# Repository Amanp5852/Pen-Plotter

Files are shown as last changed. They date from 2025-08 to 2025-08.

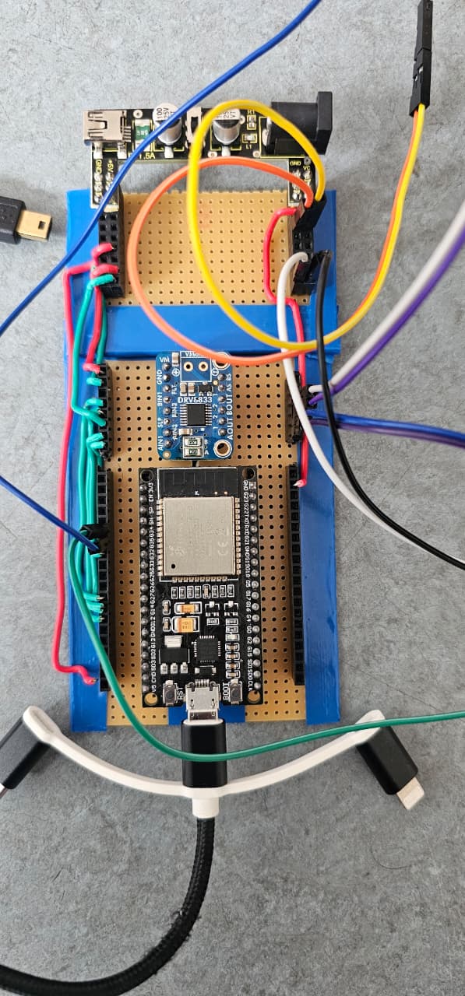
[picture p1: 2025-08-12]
Electrical_Connection/Electrical_Hardware.jpg

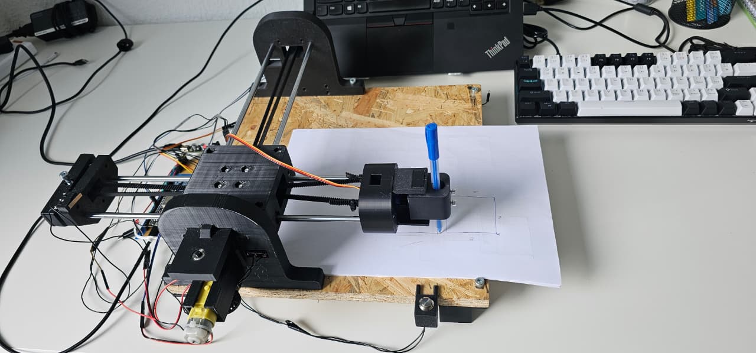
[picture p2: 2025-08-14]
Videos and Photos/Photo_Of__Pen_Plotter.jpg

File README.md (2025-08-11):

**CoreXY ESP32 Pen Plotter**
This project is a fully functional CoreXY-based pen plotter designed for precision, speed, and ease of use. It brings together mechanical engineering, electronics, control systems, and intuitive software to deliver a reliable plotting experience.

Mechanical & Hardware Features
CoreXY motion system for high-speed, precise X/Y movement with reduced inertia.

GT2 timing belts and precision drivers for smooth, consistent motion.

Custom 3D-printed components for the frame, carriage, belt tensioners, and pen holder.

Servo-driven Z-axis for controlled pen up/down motion.

Limit switches for repeatable homing and reference positioning.

Emergency stop to instantly halt motion and return safely to the home position.

Electronics & Control
Powered by an ESP32 microcontroller for fast processing and wireless capability.

PID-based closed-loop control with real-time feedback from optical encoders.

Encoder feedback ensures accurate path following, even during complex or long plots.

Software & User Interface
Custom firmware built from the ground up for CoreXY kinematics and closed-loop PID control.

User-friendly UI for easy operation — allowing you to control movements, start/stop plotting, trigger homing, and manage the emergency stop with minimal learning curve.

UI designed for accessibility, making it easy for beginners and efficient for advanced users.

Safety & Reliability
Integrated emergency stop ensures quick reaction to errors or obstructions.

Homing process guarantees consistent starting points for all drawings.

Sturdy yet lightweight structure ensures durability without sacrificing portability.

This pen plotter is not just a demonstration of precise motion control — it’s a complete system that merges mechanical design, control theory, and user-centric software into a versatile plotting tool. Whether for art, technical drawings, or experimental automation, it delivers consistent and repeatable results while keeping operation intuitive and safe.plotted artwork or technical drawings.

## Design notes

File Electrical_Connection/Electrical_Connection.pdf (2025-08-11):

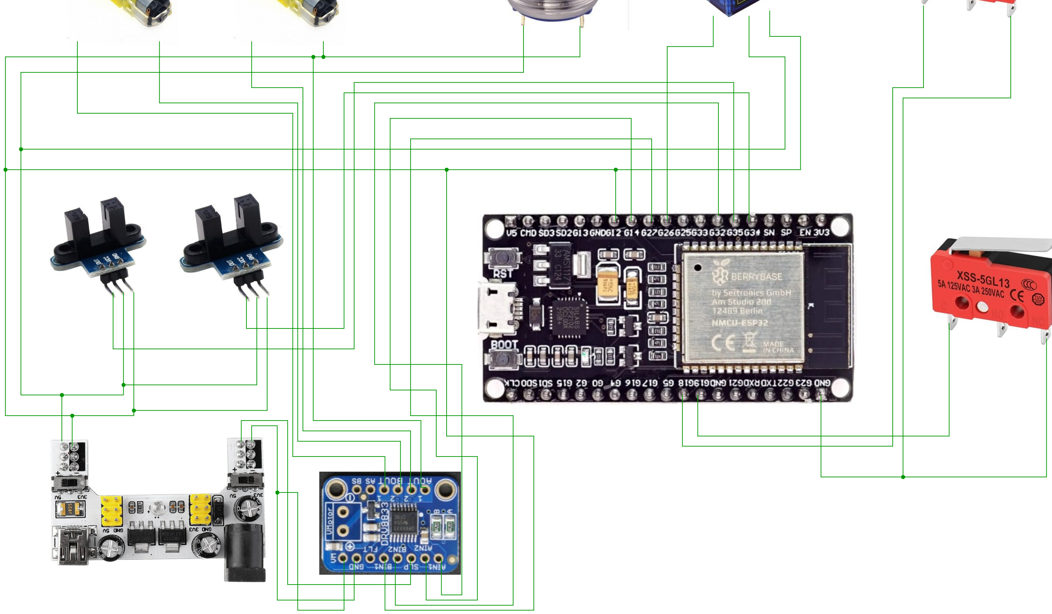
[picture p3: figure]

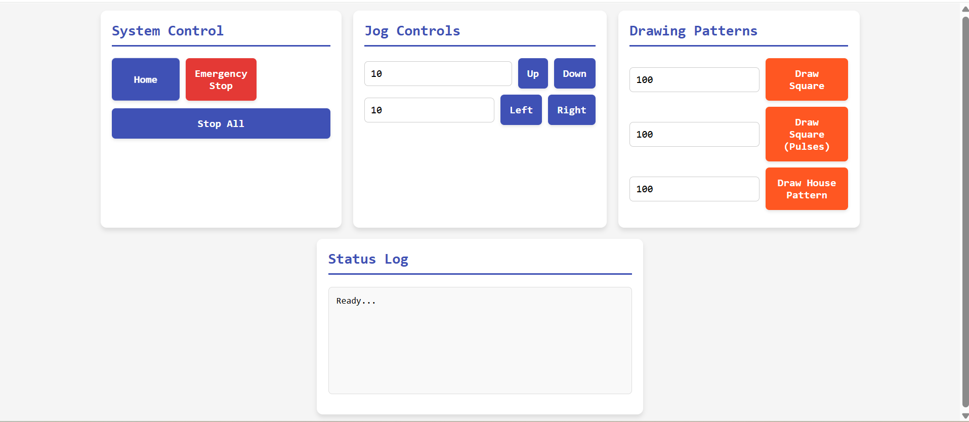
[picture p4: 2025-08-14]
Videos and Photos/Web_UI.png

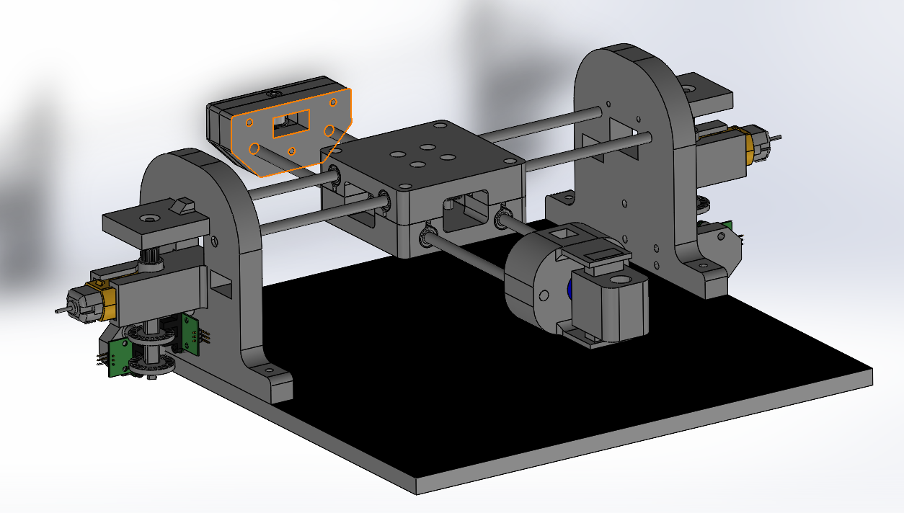
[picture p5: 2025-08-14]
Videos and Photos/CAD_Photo.png

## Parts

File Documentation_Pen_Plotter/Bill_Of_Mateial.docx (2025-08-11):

# Index of Change

Version | Description of Change | Name | Date
1.0 | Initial | Atharva Bhosale | 2025-06-20

# Table of Contents

Index of Change 1

Table of Contents 1

1 Subject 1

2 Bill of Material 2

3 Conclusion 4

# 1 Subject

A pen plotter is a type of computer-controlled device that uses pens or markers to create precise and accurate drawings on paper. This project aims to develop a functional pen plotter using specific components and technologies that showcases the integration of hardware, software, and mechanical components to achieve a specific task.

This document presents the Bill of Materials (BOM) for the pen plotter developed and fabricated by us as a part of our Workshop Mechatronics project. This product combines hardware, software, and mechanical components to create precise and accurate drawings on paper.

The BOM serves as a comprehensive inventory list, detailing the specific components and technologies utilized in the construction of the pen plotter, highlighting their crucial role in achieving the desired functionality and performance.

The Bill of Materials presented in this document provides a comprehensive inventory of the key components and technologies employed in the construction of the pen plotter.

These carefully selected components and technologies are instrumental in achieving the precise and accurate drawing capabilities of the pen plotter, showcasing its exceptional functionality and performance.

# 2 Bill of Material

Bill of Materials
Item | Description | Material | Source | QTY | Measurement | Unit Price | | Total Price

Mechanical Components
M01 | Pulley 2GT | Aluminium | Temu | 5 | piece | € 1,15 | | € 5,76
M02 | Heat Set Inserts | Steel | Temu | 200 | piece | € 0,025 | | € 4,45
M03 | Neodymium Magnet | Magnet | Conrad | 1 | piece | € 6,99 | | € 6,99
M04 | Ball Bearing | Steel | Conrad | 2 | piece | € 1,29 | | € 2,58
M05 | Geared Pulley | Steel | University | 2 | piece | € 0,20 | | € 1,00
M06 | 3D Printed Feet | PLA | University | 4 | piece | € 0,10 | | € 1,20
M07 | Belt | Rubber | University | 1 | meter | € 0,20 | | € 2,40
M08 | Smooth rods 6mm | Steel | University | 4 | meters | € 0,15 | | € 1,50
M09 | Cable ties | Plastic | Hellweg | 100 | piece | € 0,025 | | € 2,50
M10 | Super Glue | Glue | Tedi | 1 | piece | € 1,00 | | € 1,00
M11 | M3 *20mm | Steel | Hellweg | 16 | piece | € 0,211 | | € 3,39
M12 | M3 *10mm | Steel | Hellweg | 16 | piece | € 0,19 | | € 3,19
M13 | M3 Nuts | Steel | Hellweg | 20 | piece | € 0,018 | | € 3,79
M14 | M4 washers | Plastic | Hellweg | 25 | piece | € 0,079 | | € 1,99
M15 | M4 Screws | Steel | University | 4 | piece | € 0,00 | | € 0,00
| | | | | | | Subtotal | | € 41,74

Electrical Components
E01 | Bread Board | | University | 2 | Piece | € 0 | | € 0
E02 | Connect Socket Strip | | Conrad | 12 | Piece | € 0,29 | | € 3,48
E03 | Dupont Connector Kit | | Berrybase | 1 | Piece | € 14,85 | | € 14,85
E04 | Motor Driver | | University | 1 | Piece
E05 | ESP32 Development board | | University | 1 | Piece
E06 | TT Motor Encoder | | University | 2 | Piece
E07 | Servo motor | | University | 2 | Piece
E08 | Cable for Motor Driver | | University | 1 | Piece
E09 | Cable for Power Supply | | University | 1 | Piece
E10 | Jumper cables | | University | 1 | Piece
E11 | DC Motor | | University | 2 | Piece
E12 | Power Supply Unit | | University | 1 | Piece
E13 | Hall Effect Sensor | | University | 1 | Meter
E14 | Microswitch RED | | University | 4 | Piece
E15 | Adaptor 12V | | Amazon | 1 | Piece | € 15 | | € 15
E16 | Limit Switches | | Univesity | 4 | Piece
E17 | Perfboard | | Conrad | 1 | Piece | € 2,49 | | € 2,49
| | | | | | | Subtotal | | € 35,82

3D Printed Components
P01 | Encoder Wheel | PLA | University Lab | 4 | Piece | € 1,00 | | € 2,00
P02 | GT2 15T Motor Pulley | PLA | University Lab | 2 | Piece | € 1,00 | | € 2,00
P03 | Carriage | PLA | University Lab | 1 | Piece | € 5,0 | | € 5,00
Item | Description | Material | Source | QTY | Measurement | Unit Price | | Total Price
P04 | Pulley Tensioner | PLA | University Lab | 1 | Piece | € 6.00 | | € 6,00
P05 | Motor Support Fixture | PLA | University Lab | 2 | Piece | € 11.00 | | € 22,00
P06 | Pen Holder Fixture | PLA | University Lab | 1 | Piece | € 8.00 | | € 8,00
P07 | Base Plate | PLA | University Lab | 1 | Piece | € 20.00 | | € 20,00
P08 | Pulley Tensioner | PLA | University Lab | 1 | Piece | € 16.00 | | € 16,00
| | | | | | | Subtotal | | € 61
Grand total | | | | | | | | | € 138.56

# 3 Conclusion

The total cost of manufacturing the pen plotter is approximately 175 euros, which is significantly less than the permitted cap of 200 euros and in accordance with User requirements.

– end of document –

Bill of Material (BOM) XY-Pen Plotter XYPP_14_006-BOM.docx Doc. # XYPP Version: 1.0 Date: 2025-06-20 page: of Project #: XYPP

B|BRAUN Sharing Expertise CoE Automateted Infusion Systems Testplan Produkt Titel D:\MERO\SEM 2\Workshop_Mechatronics_II_MERO_2023\Documentation\16.07.23\XYPP_14_006-BOM.docx Dokument-Nr.: Nr. eingeben Version: X.0 Datum: 200X-XX-XX Seite: von Änderung-Nr.: CXX-YYY

Validation Report XY-Pen Plotter Doc. # XYPP Version: 1.0 Date: 2025-06-20 page: of Project #: XYPP

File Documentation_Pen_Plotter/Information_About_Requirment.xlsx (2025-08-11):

Project Name |  |  | XY-Pen Plotter- MERO 24
Date |  |  | WS24/25
Version |  |  | V2
Group Name |  |  | MER0 Team 10
Group Members |  |  | Aman Patel, Vighnesh Deshmukh, Atharva Bhosale, Rishab deshkar, Deep Shah
User Requirement |  |  |  |  |  |  | Technical Specification |  |  |  |  |  |  |  | Design Specification |  |  |  |  |  |  | Verification Protocol |  |  |  |  |  |  | Verification Report |  |  |  |  |  |  |  |  |  | Validation Protocol |  |  |  |  |  | Validation Protocol
UR # | module | Title | User Requirement | Remark | Domain (HW/SW/ME/all) | Must / Wish | TS # | ref. to UR # | module | Title | Technical Requirement | Remark | Domain (HW/SW/ME/all) | Must / Wish | DS # | ref. to TS # | module | Reference (# bill of materials, article # supplier part, ref. doc # etc..) to implementation | Description | Remark | Domain (HW, SW, ME, all) | VerP # | ref to TS # | module | test procedure (description of routine) | verification criterion | ref. # (i.e. test protocol,etc.) | Domain (HW/SW/ME/all) | VerR # | ref. to VerP # | module | test function (to be copied from verification protocol) | nominal criterion, target value | actual value | criterion passed / failed | remark | ref. # (i.e. test report, etc.) | Domain (HW/SW/ME/all) | ValP # | ref. to UR # | module | validation procedure (description of routine) | ref. # (i.e. validation protocol, customer test, etc..) | vaidation criteria | ValR # | ref. to ValP # | module | criteria passed / failed | ref. # (i.e. test report, etc.)
UR_1 | General | Intended Use | The XY-pen plotter is designed to draw a Nikolaus house based on programmed instructions and is intended for educational use by MeRo Master’s students in the university laboratory. |  | all |  | TS_1 | UR_1 | General | Intended Use | The pen plotter can be used by the students to draw niclolaus house. |  | all |  | DS_1 | TS_1 | General | M01-M16, E01-E16, P01-P07 | The system uses DC motors with encoders to drive the X and Y axes and a servo motor for Z-axis (pen lift). An ESP32 microcontroller interprets programmed code instructions for the Nikolaus house and controls motor speed and direction. The interface allows students to upload drawing commands from a PC or mobile device through Wi-Fi. |  | all | VerP1 | TS_1 | General | Upload Nikolaus house code via Wi-Fi; observe drawing behavior. | Verify drawing accuracy and instruction interpretation via ESP32. | Test protocol doc# 01_MERO_VerP | all |  | VerP1 | General | Verify drawing accuracy and instruction interpretation via ESP32. | Pen plotter completes Nikolaus house with proper scale, direction, and without manual intervention. | Pen Plotter completes Nikolaus Hause but with some errors in corner matching. (Atleast at the initial run) | Passed (Still optimization is required) |  | Test protocol doc# 01_MERO_VerP | all | ValP 1 | UR01, UR10, UR11 | General | Upload Nikolaus House drawing code via GUI. Run plot. Repeat 10 times and overlay outputs to check dimensional accuracy. | ValP_01 | All 10 plots complete without error; overlay deviation ≤ ±3mm | VaIR1 | ValP_01 | General | Passed
UR_2 | General | Focus Group (User and Client) | Laboratory, Academic and Research institutions, Industries. |  | HW |  | TS_2 | UR_2 | General | Focus Group (User and Client) | The pen plotter is designed for Laboratory, Academic and Research institutions, Industries to use. |  | HW |  | DS_2 | TS_2 | General | M01-M16, E01-E16, P01-P07 | Design the system with modular hardware and open-source firmware for ease of use, modification, and learning in educational and research institutions. |  | HW | VerP2 | TS_2 | General | Attempting hardware module replacement; test firmware re-flashing (During the testing of the codes for refinement) | Assess modularity and open-source accessibility. |  | HW |  | VerP2 | General | Assess modularity and open-source accessibility. | User modifies hardware and uploads custom firmware within 10 minutes. | Made the input code run in order to optimize the system. Also changed many parts and assembly carried out within the range of 10 minutes | Passed |  |  | HW | ValP 2 | UR07, UR23, UR39 | Functional & non functional Requirement | Allow 2 non-project students to operate the GUI. Ask them to plot Nikolaus House and perform pen-up/pen-down. | VaIP_02 | User can complete task independently in <5 min after <2 min instruction | VaIR 2 | VaIP_02 | Functional & non functional Requirement | Passed
FOCUS APPLICATION
UR_3 | Use Cases | Focus Application | The plotter must draw the Nikolaus house continuously without any interruptions |  | all |  | TS_3 | UR_3 | Use Cases | Focus Application | The Nicolaus house can be drawn without any difficulties. |  | all |  | DS_3 | TS_3 | Use Cases | M01-M16, E01-E16, P01-P07 | Implement buffer handling and continuous motor control to ensure uninterrupted drawing operations; incorporate fault-tolerant firmware to recover from minor disturbances without halting. |  | all | VerP3 | TS_3 | Use Cases | Introduce signal noise or small power dip. Monitor for continued operation. | Verify uninterrupted operation under minor disturbances. |  | all |  | VerP3 | Use Cases | Verify uninterrupted operation under minor disturbances. | Drawing continues without stopping or significant deviation. | The amount of the vibration measured was minimal, not have means to provide quantitative value. | Passed |  |  | all | VaIP 3 | UR06, UR14, UR26 | Functional & non functional Requirement | Place 1kg weight on center carriage for 1 hour. Measure deflection using Vernier caliper. | ValP_03 | Deflection under load < 1.5mm after 1hr | VaIR 3 | ValP_03 | Functional & non functional Requirement | Passed
UR_4 | Use Cases | Focus Application | The user should be able to run the plotter without the pen touching the surface, for testing. |  | HW |  | TS_4 | UR_4 | Use Cases | Focus Application | In dry-run mode, Z-axis servo stays in “pen up” position throughout the plot to simulate movement without drawing. |  | all |  | DS_4 | TS_4 | Use Cases | M01-M16, E01-E16, P01-P07 | Firmware includes a dry-run flag that disables Z-axis pen-down commands. Servo is locked in the “pen up” PWM signal range. Verified through V&V dry-run testing. |  | HW | VerP4 | TS_4 | Use Cases | Enable dry-run; command plot of Nikolaus house giving the hard coding to implement. Check for no pen contact. | Validate dry-run feature. | Test protocol doc# 04_MERO_VerP | HW |  | VerP4 | Use Cases | Validate dry-run feature. | Plot completes in air without touching surface. | Plot completes the dry run with no actuation of Z axis | Passed |  | Test protocol doc# 04_MERO_VerP | HW | VaIP 4 | UR08, UR32, UR42 | Functional & Market requirement | Disassemble plotter. Replace motor, pen holder, and tensioner using STL parts and bolts. Time the process. | VaIP_4 | Full disassembly and reassembly <25 min. No tools except hex key. | VaIR 4 | VaIP_4 | Functional & Market requirement | Passed
APPLICATION SITE
UR_5 |  | Application Site (Industrial, Home, etc.) | The pen plotter must be suitable and safe for use in typical indoor educational and lab environments. |  | all |  | TS_5 | UR_5 |  | Application Site (Industrial, Home, etc.) | The pen plotter shall operate in 15–30 °C, ≤60% humidity, emit ≤50 dB noise, and comply with IEC 61010 indoor safety standards. | Environmental conditions comply with IEC 61010 for indoor educational equipment—ensuring safe operation at 15–30 °C, ≤60% humidity, and noise emissions ≤50 dB for classroom/lab use. | all |  | DS_5 | TS_5 |  | M01-M16, E01-E16, P01-P07 | Use enclosed ABS housing for IEC 61010 compliance; integrate low-noise DC motors for X/Y and a micro servo for Z; add passive vents for cooling. | Environmental conditions comply with IEC 61010 for indoor educational equipment—ensuring safe operation at 15–30 °C, ≤60% humidity, and noise emissions ≤50 dB for classroom/lab use. | all | VerP5 | TS_5 | 0 | Run plotter for 30 minutes; measure temperature; inspect casing. | Safety and thermal compliance check. |  | all |  | VerP5 |  | Safety and thermal compliance check. | Surface temperature < 50°C, no exposed high voltage parts. | Unfortunately we don't have any means to check the temperature | Under Work |  |  | all | VaIP 5 | UR28, UR29, UR38 | Functional, regularity requirement and standard | While plotting, press E-stop. Record time to halt and return to home. Then simulate power cut and resume from saved position. | VaIP_5 | System halts <5s, homes <10s. Resumes correctly after restart. | VaIR 5 | VaIP_5 | Functional, regularity requirement and standard | Passed
FUNCTIONAL REQUIREMENT
UR_6 | General | Functional Requirements | Must be durable and not bend under motor loads |  | ME |  | TS_6 | UR_6 | General | Functional Requirements | The material must be lightweight, durable, and resist bending under motor loads. |  | ME |  | DS_6 | TS_6 | General | P01-P07 | The base plate is made from acrylic or PLA with a strength rating of up to 16 MPa to ensure durability under motor load. |  | ME | VerP6 | TS_6 | General | Applying physical load on the center carriage to check for any bulging | Mechanical strength test of base. | Test protocol doc# 06_MERO_VerP | ME |  | VerP6 | General | Mechanical strength test of base. | Base withstands 16 MPa stress without deformation. | Placed a load of 1kg over a period of 1 hour and verified the structural accuracy using vernier calipers and it was within the own acceptable range of 1mm. | Passed |  | Test protocol doc# 06_MERO_VerP | ME | VaIP 6 | UR04, UR15, UR22 | Use application and functional requirement | Enable dry-run mode. Execute Nikolaus House command. Observe that Z-axis servo remains inactive (pen stays lifted). | VaIP_6 | No pen contact during dry run. Servo should not actuate. | VaIR 6 | VaIP_6 | Use application and functional requirement | Passed
UR_7 | General | Functional Requirements | The user interface should be easy to understand and operate |  | SW |  | TS_7 | UR_7 | General | Functional Requirements | The user interface is very simple and operation can be started by a single click of the button. |  | SW |  | DS_7 | TS_7 | General |  | FluidNC firmware is used, providing a web-based interface with one-click controls for starting, pausing, and stopping plot jobs. |  | SW | VerP7 | TS_7 | General | Checking the manipualtion of assembly via the GUI on web. To verify it using a third party person to check for user-friendliness. | User interface operability test. | Test protocol doc# 07_MERO_VerP | SW |  | VerP7 | General | User interface operability test. | User completes operation cycle without external guidance. | We test the plot and its friendliness with two of the students from different branch and took their response, which at first was not convincing and after the modification, we find it positive | Passed |  | Test protocol doc# 07_MERO_VerP | SW | VaIP7 | UR22, UR27 | Functional requirement | Send pen-lift and pen-lower commands. Measure servo response time using stopwatch or camera. | VaIP_7 | Servo completes toggle (up/down) in <500ms | VaIR 7 | VaIP_7 | Functional requirement | Passed
UR_8 | General | Functional Requirements | Easily assembled and disassembled |  | ME |  | TS_8 | UR_8 | General | Functional Requirements | The frame must support easy assembly and disassembly for future modifications. |  | ME |  | DS_8 | TS_8 | General | P01-P07 | Frame uses snap-fit joints and bearings to allow easy disassembly and future upgrades. |  | ME | VerP8 | TS_8 | General | Provided disassembled kit and tools. Measure time for setup/teardown and ease of the assembly. | Assembly and disassembly trial. | Test protocol doc# 08_MERO_VerP | ME |  | VerP8 | General | Assembly and disassembly trial. | Full setup/disassembly within 20 minutes. | Total time for dissembling and Assembly took around 22minutes | Barely failed |  | Test protocol doc# 08_MERO_VerP | ME | VaIP 8 | UR19, UR20, UR42 | Functional & other non functional requirement | Test fitment of pens with diameters 8mm, 10mm, 12mm, 13mm. Insert into mount with/without heat-insert nut. Observe for stability and slippage. | VaIP_8 | All 4 sizes must fit securely with <1mm misalignment or slippage | VaIR 8 | VaIP_8 | Functional & other non functional requirement | Passed
UR_9 | General | Functional Requirements | The plotter should power down safely after inactivity. |  | HW |  | TS_9 | UR_9 | General | Functional Requirements | Include a timeout function to power down motors after inactivity. |  | HW |  | DS_9 | TS_9 | General |  | Timer in firmware deactivates PWM signal to motors if idle for set time (e.g., 10 minutes). |  | HW | VerP9 | TS_9 | General | Leaving system idle after partial operation. Observe behavior. | Idle timeout behavior. |  | HW |  | VerP9 | General | Idle timeout behavior. | Motors powered down and safe after 10 minutes of inactivity. | Motors and drivers powered down; ESP32 enters low-power state or disables outputs. That part of coding is implemented to achieve the same. | Passed |  |  | HW
UR_10 | Specific Function | Functional Requirements | The pen plotter must produce precise drawings with consistent line placement and minimal deviation. |  | all |  | TS_10 | UR_10 | Specific Function | Functional Requirements | The system shall achieve a positional accuracy of ±0.5 mm across the full drawing area and maintain repeatability within ±0.2 mm under normal operation. |  | all |  | DS_10 | TS_10 | Specific Function | P01, E01,E04,E05,E17 | Use rotary encoders on the DC motors (X and Y axes) for closed-loop feedback control. Implement PID tuning in firmware for precision correction. |  | all | VerP10 | TS_10 | Specific Function | Move to fixed XY coordinates; measure pen endpoint deviation. Checking the directional accuracy. | Evaluate feedback precision via encoders. | Test protocol doc# 10_MERO_VerP | all |  | VerP10 | Specific Function | Evaluate feedback precision via encoders. | Line deviation under ±2 mm. | Till now as per the test runs we have performed, we are getting dimensional tolerance -2.5 to 3mm at the corner meeting. Still refining. | Under Work |  | Test protocol doc# 10_MERO_VerP | all
UR_11 | Specific Function | Functional Requirements | The pen plotter should precisely draw the Nicolas house without any irregularities. |  | all |  | TS_11 | UR_11 | Specific Function | Functional Requirements | High-precision drawing of Nicolaus's house is achieved using sensors like the hall effect and with a sturdy design. |  | all |  | DS_11 | TS_11 | Specific Function |  | Use gear-reduced DC motors with basic encoder feedback and PID control to achieve ±2 mm accuracy. |  | all | VerP11 | TS_11 | Specific Function | Run 10 cycles of Nikolaus house. Overlay results. Check for the dimensional accuracy. | Repeated drawing precision test. | Test protocol doc# 11_MERO_VerP | all |  | VerP11 | Specific Function | Repeated drawing precision test. | Variability in line placement < 2 mm across runs. | Dimensional accuracy worsens as we run more and more cycle due to heating of the motor. Dimensional accuracy after ten cycle was with tolerance +/-4mm. | Under Work |  | Test protocol doc# 11_MERO_VerP | all
UR_12 | Specific Function | Functional Requirements | The pen plotter should have 2 Degrees of freedom in the X and Y directions. |  | ME |  | TS_12 | UR_12 | Specific Function | Functional Requirements | Pen plotter has 2 degrees of freedom in x and y direction. |  | ME |  | DS_12 | TS_12 | Specific Function | P01,E11,E07,P06 | X and Y DOF are implemented using DC motors with belt-drive mechanisms. A servo motor provides vertical actuation (Z-axis) for pen lift and placement. |  | ME | VerP12 | TS_12 | Specific Function | Command diagonal and axis-specific motion. Observe paths. Check the actuation accuracy. | Validate 2 DOF motion. |  | ME |  | VerP12 | Specific Function | Validate 2 DOF motion. | Independent and combined X/Y movement accurate. | Made independent codes for X and Y actuation and considerable results in accuracy is achieved | Passed |  |  | ME
UR_13 | Specific Function | Functional Requirements | Duration for operation should be minimal. |  | SW |  | TS_13 | UR_13 | Specific Function | Functional Requirements | Nicolaus house can be drawn within a time span of 1.5 minutes. |  | SW |  | DS_13 | TS_13 | Specific Function |  | Use high-RPM DC motors for faster X and Y movement. Optimize firmware with minimal delay and efficient path planning to reduce total drawing time. |  | SW | VerP13 | TS_13 | Specific Function | Run identical job with optimized vs. unoptimized firmware. Check for different values of PID control to have more accuracy. | Time optimization check. |  | SW |  | VerP13 | Specific Function | Time optimization check. | Optimized runtime at least 20% faster. |  | Under Work |  |  | SW
UR_14 | Specific Function | Functional Requirements | It should be strudy enough to abosrb vibrations of the system |  | ME |  | TS_14 | UR_14 | Specific Function | Functional Requirements | The base must be solid enough to minimize vibrations during plotter operation. |  | ME |  | DS_14 | TS_14 | Specific Function | M05 | A wooden base is used to provide a sturdy foundation and absorb vibrations during operation. |  | ME | VerP14 | TS_14 | Specific Function | Carrying out the run on wooden block and without it, and measure for the dimensional accuracy reached by the pen plotter. | Vibration dampening check. |  | ME |  | VerP14 | Specific Function | Vibration dampening check. | Vibration amplitude < 0.3 g during operation. | We just manually check the sturdiness, as we don’t have means to calculate the vibration and damping. | Passed |  |  | ME
UR_15 | Specific Function | Functional Requirements | The surface should be Smooth to accommodate clear drawing. |  | ME |  | TS_15 | UR_15 | Specific Function | Functional Requirements | The surface must be smooth to ensure accurate and clear line drawing. |  | ME |  | DS_15 | TS_15 | Specific Function | P08 | A 3D-printed base is attached on top to ensure a smooth surface for precise and clean drawing. |  | ME | VerP15 | TS_15 | Specific Function | Draw continuous straight lines. Inspect for wobble/ink pooling. | Surface finish check. | Test protocol doc# 15_MERO_VerP | ME |  | VerP15 | Specific Function | Surface finish check. | Smooth lines without breaks or ink bleeding. | Tailored made line commands provided and vertical accuracy achieved was within the tolerance of +/-2mm | Passed |  | Test protocol doc# 15_MERO_VerP | ME
UR_16 | Specific Function | Functional Requirements | Grippers must be used to encapsulate the corners of the base plate to securely hold the paper in position. |  | ME |  | TS_16 | UR_16 | Specific Function | Functional Requirements | The paper must remain fixed in position during operation using proper holding mechanisms. |  | ME |  | DS_16 | TS_16 | Specific Function | M03 | Magnetic couplers are used at the corners of the base plate to securely hold the paper in place during plotting. |  | ME | VerP16 | TS_16 | Specific Function | Shake plotter frame with paper mounted. Observe for play in between the base and paper. | Paper securement test. | Test protocol doc# 16_MERO_VerP | ME |  | VerP16 | Specific Function | Paper securement test. | Paper shifts < 0.5 mm. | Shaken the base frame in which paper Is clamped and it is afixed using strong permanent magnets and provides suitable rigidity of <0.3mm. | Passed |  | Test protocol doc# 16_MERO_VerP | ME
UR_17 | Specific Function | Functional Requirements | It should be strudy enough to abosrb vibrations of the system |  | ME |  | TS_17 | UR_17 | Specific Function | Functional Requirements | The base must be solid enough to minimize vibrations during plotter operation. |  | ME |  | DS_17 | TS_17 | Specific Function | M05 | A wooden base is used to provide a sturdy foundation and absorb vibrations during operation. |  | ME | VerP17 | TS_17 | Specific Function | Carrying out the run on wooden block and without it, and measure for the dimensional accuracy reached by the pen plotter. | Vibration dampening check. |  | ME |  | VerP17 | Specific Function | Vibration dampening check. | Vibration amplitude < 0.3 g during operation. | We just manually check the sturdiness, as we don’t have means to calculate the vibration and damping. | Passed |  |  | ME
UR_18 | Specific Function | Functional Requirements | smooth sliding of axis units, rattle-free movements, |  | ME |  | TS_18 | UR_18 | Specific Function | Functional Requirements | The frame must ensure smooth sliding of axes with minimal rattle or friction. |  | ME |  | DS_18 | TS_18 | Specific Function | M01,M06 | GT2 belts and linear bearings are used to ensure smooth and rattle-free motion of moving axes. |  | ME | VerP18 | TS_18 | Specific Function | Oscilloscope on encoder feedback; audio analysis for rattling. | Motion smoothness test. | Test protocol doc# 18_MERO_VerP | ME |  | VerP18 | Specific Function | Motion smoothness test. | Uniform feedback waveform; sound < 50 dB. | We have plotted the response of the encoder for previous design and we found it not optimum, hence design changes being made and it will much more optimum | Under Work |  | Test protocol doc# 18_MERO_VerP | ME
UR_19 | Specific Function | Functional Requirements | Pen holders should have a firm grip to prevent the pen from slipping out of the holder. |  | ME |  | TS_19 | UR_19 | Specific Function | Functional Requirements | The pen holder must support pens of varying sizes. |  | ME |  | DS_19 | TS_19 | Specific Function | M02 | Heat insert nuts are embedded in the pen holder to ensure secure tightening and grip. |  | ME | VerP19 | TS_19 | Specific Function | Attach pen without the heat insert nuts, run plot; monitor for slippage. | Pen grip test. | Test protocol doc# 19_MERO_VerP | ME |  | VerP19 | Specific Function | Pen grip test. | No visible slipping or tilt. | Attached the pen with just the glue on front mount and draw some lines and with same command code but with pencil held in heat insert nut is checked. Considerable result in the accuracy observed with around 50 - 60% better. | Passed |  | Test protocol doc# 19_MERO_VerP | ME
UR_20 | Specific Function | Functional Requirements | It should be able to accommodate different types of pen. |  | ME |  | TS_20 | UR_20 | Specific Function | Functional Requirements | The pen plotter can accommodate pens of different sizes with screw adjustment. |  | ME |  | DS_20 | TS_20 | Specific Function | P06 | A 13 mm diameter adjustable slot is included to accommodate pens of different sizes. |  | ME | VerP20 | TS_20 | Specific Function | Insert pens of 8mm, 10mm, 12mm, 13mm diameter. Test all. | Pen size accommodation check. | Test protocol doc# 20_MERO_VerP | ME |  | VerP20 | Specific Function | Pen size accommodation check. | All pens held securely and operate without misalignment. | We tried to insert pen and pencil of variable diameter and all fits well because of modular design and almost bare minimum misalignment. | Passed |  | Test protocol doc# 20_MERO_VerP | ME
UR_21 | Specific Function | Functional Requirements | The plotter should accept input from the user, such as text or SVG image files. |  | SW |  | TS_21 | UR_21 | Specific Function | Functional Requirements | Use a microcontroller (e.g., Arduino, ESP32) with serial/USB interface |  | SW |  | DS_21 | TS_21 | Specific Function | E05 | ESP32 used as the controller; USB or Wi-Fi interface depending on the selected microcontroller. |  | SW | VerP21 | TS_21 | Specific Function | Upload the customized code for different operation like PWM check, Motor direction and reverse etc. and check for the response for transmitting and receiving. | Command input format validation. | Test protocol doc# 21_MERO_VerP | SW |  | VerP21 | Specific Function | Command input format validation. | All command formats processed correctly. | Prepared unique codes to first check the RPM, one to count the encoder and direction and custom code to allow diagonal movement. All went successful | Passed |  | Test protocol doc# 21_MERO_VerP | SW
UR_22 | Specific Function | Functional Requirements | The plotter should lift or lower the pen for writing and moving. |  | SW |  | TS_22 | UR_22 | Specific Function | Functional Requirements | Servo motor to control Z-axis pen up/down mechanism. |  | SW |  | DS_22 | TS_22 | Specific Function | E07 | Servo motor mounted on Z-axis to lift/lower pen. |  | SW | VerP22 | TS_22 | Specific Function | Send lift/lower commands; monitor servo response. | Pen lift test. | Test protocol doc# 22_MERO_VerP | SW |  | VerP22 | Specific Function | Pen lift test. | Servo toggles positions within 500 ms. | We checked toggle down and toggle up command to actuate servo motoe and calcualted response time was withing 500ms. | Passed |  | Test protocol doc# 22_MERO_VerP | SW
UR_23 | Specific Function | Functional Requirements | The plotter should support connection to a computer or mobile device. |  | SW |  | TS_23 | UR_23 | Specific Function | Functional Requirements | Enable USB or wireless (Wi-Fi via ESP32) communication with the host system. |  | SW |  | DS_23 | TS_23 | Specific Function |  | Wi-Fi connectivity via ESP32 module provided as a communication module. |  | SW | VerP23 | TS_23 | Specific Function | Connect plotter to PC/mobile via Wi-Fi. Test commands. | Connectivity test. | Test protocol doc# 23_MERO_VerP | SW |  | VerP23 | Specific Function | Connectivity test. | Stable connection with < 7 sec response delay. | Stable response achieved via Wifi connectivity of web interface the pen plotter and calculated response time was withing 7sec. | Passed |  | Test protocol doc# 23_MERO_VerP | SW
UR_24 | Specific Function | Functional Requirements | The plotter should move smoothly in X and Y directions. |  | ME |  | TS_24 | UR_24 | Specific Function | Functional Requirements | Motion using GT2 belts and pulleys with tensioners; DC motors with PWM speed control. |  | ME |  | DS_24 | TS_24 | Specific Function |  | GT2 belt + pulley system driven by two DC motors with tensioning brackets; PWM control via motor driver IC. |  | ME | VerP24 | TS_24 | Specific Function | Measure travel using ruler over set code inputs provided on to the microcontroller. Check different tensioning using nuts and measure for the accuracy. | XY travel consistency. | Test protocol doc# 24_MERO_VerP | ME |  | VerP24 | Specific Function | XY travel consistency. | Positional error < 2 mm. | Positional accuracy achieved till now >2mm, still we are optimizing via PID control. | Under Work |  | Test protocol doc# 24_MERO_VerP | ME
UR_25 | Specific Function | Functional Requirements | The plotter should track its position precisely. |  | all |  | TS_25 | UR_25 | Specific Function | Functional Requirements | Use optical encoders on both axes for position feedback. |  | all |  | DS_25 | TS_25 | Specific Function | P01 | Two-channel rotary encoders attached to both X and Y motors. |  | all | VerP25 | TS_25 | Specific Function | Move to known points, compare encoder count to expected (Manual count using the PPR and RPM counts). | Position tracking accuracy. | Test protocol doc# 25_MERO_VerP | all |  | VerP25 | Specific Function | Position tracking accuracy. | Tracking deviation < 10%. | Deviation measure till now is more than the 10% due to various known reasons, we are working on it to optimize. | passed |  | Test protocol doc# 25_MERO_VerP | all
UR_26 | Specific Function | Functional Requirements | The system should adjust motor speed and direction based on actual position. |  | HW |  | TS_26 | UR_26 | Specific Function | Functional Requirements | Implement PID control using encoder feedback for accurate motion in X and Y axes. |  | HW |  | DS_26 | TS_26 | Specific Function |  | Firmware-integrated PID algorithm (e.g., custom code) adjusting motor speed based on encoder feedback. |  | HW | VerP26 | TS_26 | Specific Function | Introduce load while plotting; observe speed adjustment and dimensional accuracy. | PID loop test. | Test protocol doc# 26_MERO_VerP | HW |  | VerP26 | Specific Function | PID loop test. | Speed correction within 2sec. | We placed a load of the 500gm over the front mount and speed correction achieved is not not under acceptable limit. | Failed (Working on it) |  | Test protocol doc# 26_MERO_VerP | HW
UR_27 | Specific Function | Functional Requirements | The pen should touch the paper with consistent pressure. |  | ME |  | TS_27 | UR_27 | Specific Function | Functional Requirements | Use spring-based pen mount to absorb misalignment and ensure reliable pen-paper contact. |  | ME |  | DS_27 | TS_27 | Specific Function |  | Pen holder has vertical spring mount to maintain downward force and compensate uneven surfaces. |  | ME | VerP27 | TS_27 | Specific Function | Use force sensor on pen during plotting. | Pressure consistency test. | Test protocol doc# 27_MERO_VerP | ME |  | VerP27 | Specific Function | Pressure consistency test. | Variation within ±10% of average force. |  | Removed |  | Test protocol doc# 27_MERO_VerP | ME
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

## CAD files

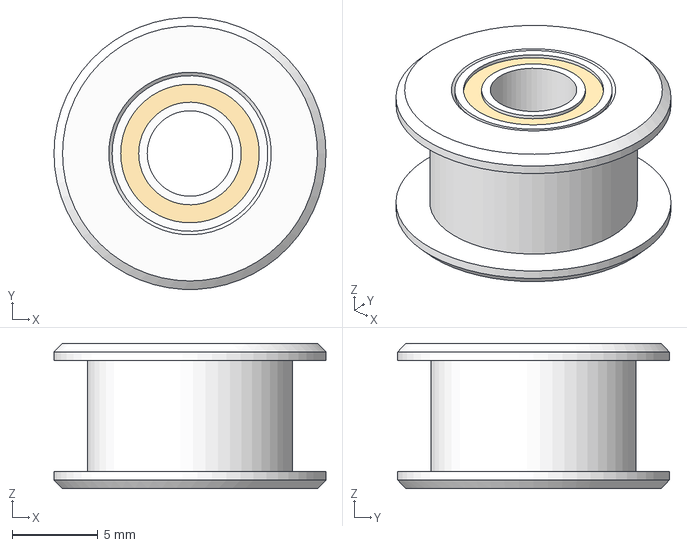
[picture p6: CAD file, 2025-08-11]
CAD_Files/Smooth_Pulley_For_Center_Assembly.stp
15.9 x 15.9 x 8.50 mm

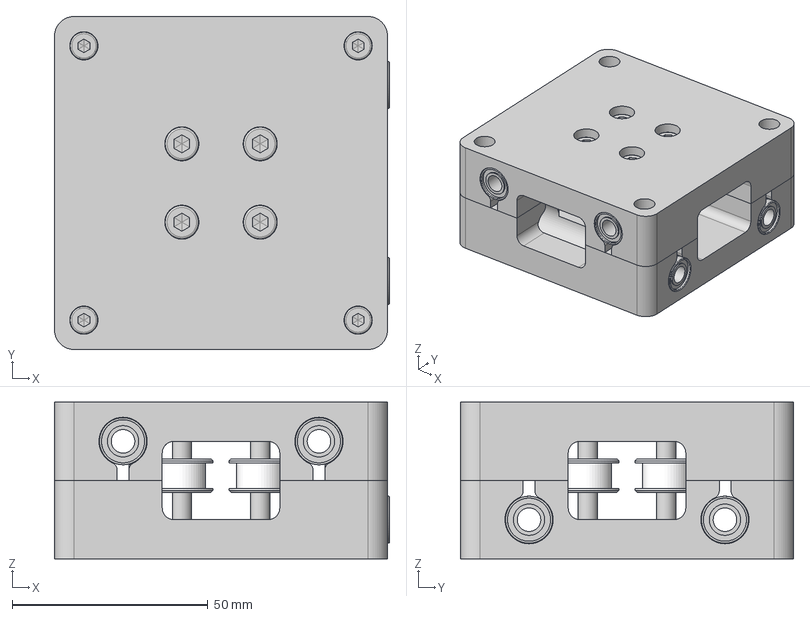
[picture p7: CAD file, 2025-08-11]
CAD_Files/Central_Assembly.stp
85.5 x 85.0 x 40.0 mm
TOP
BOTTOM
Bear x 8
DIN EN ISO 4762 - M5 x 30 Steel 4.6 Plain x 4
DIN EN ISO 4762 - M4 x 30 Steel 4.6 Plain x 4
GT2 idler pulley (5 mm bore) v1 x 4

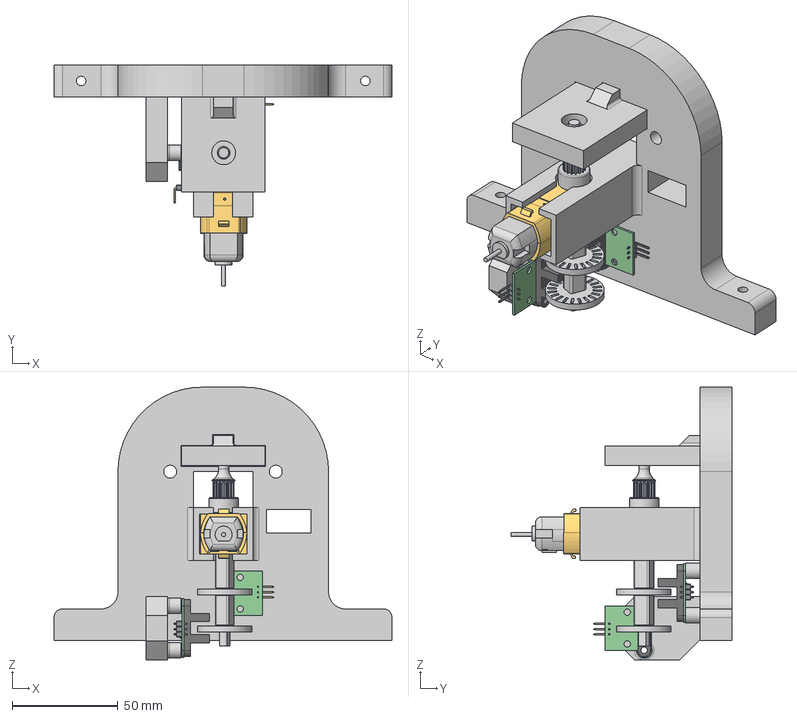
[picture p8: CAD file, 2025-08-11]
CAD_Files/Entire_Motor_Mount.stp
160.0 x 104.5 x 129.1 mm
mount
bearing holder
90deg pin header (Adegbuyi Adeyemi) x 6
SOIC8 x 2
Shaft
Motor_1
Gear box
base
encoder v8 x 2
diff
encoder2 mount

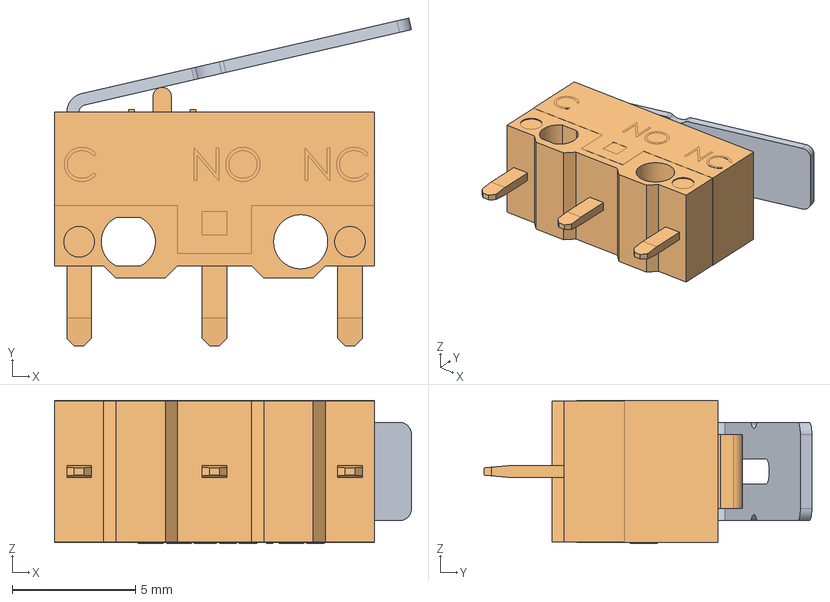
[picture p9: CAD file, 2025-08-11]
CAD_Files/Limit_Switch.stp
14.5 x 13.3 x 5.81 mm

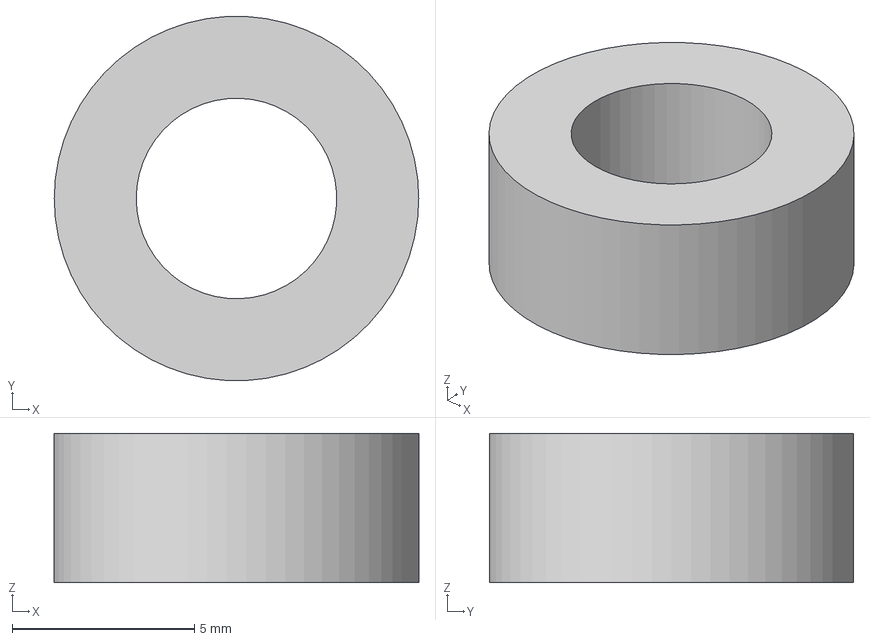
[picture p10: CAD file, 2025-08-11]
CAD_Files/Spacer_For_Alignment.stp
10.0 x 9.99 x 4.10 mm

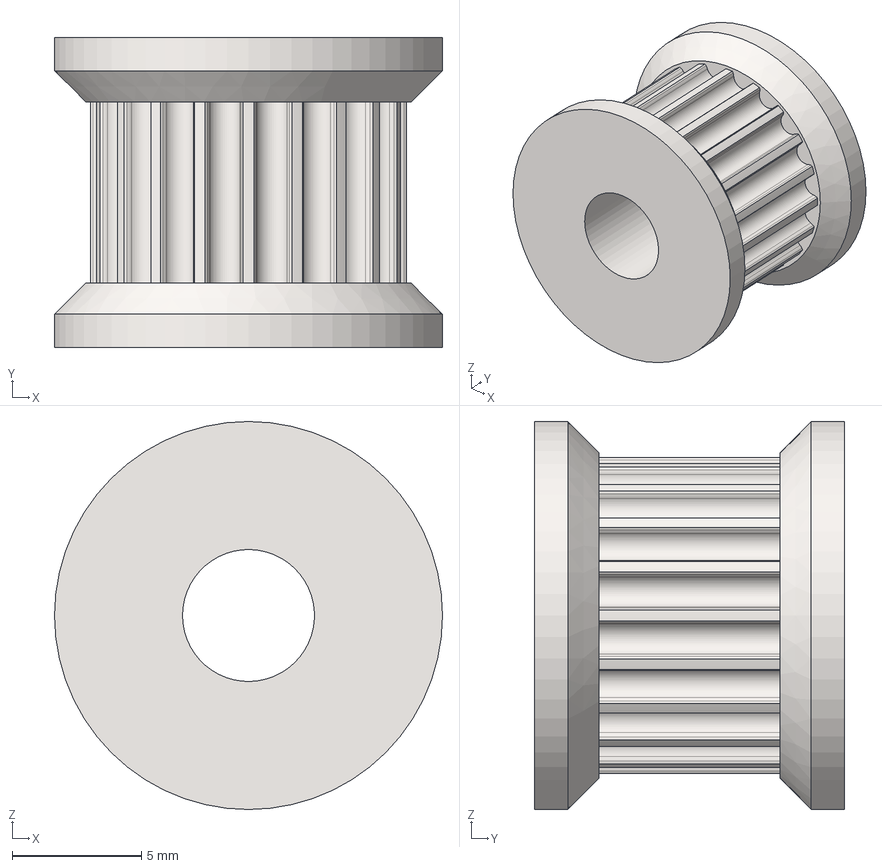
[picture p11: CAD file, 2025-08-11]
CAD_Files/Idler_Pulley.stp
15.0 x 12.0 x 15.0 mm

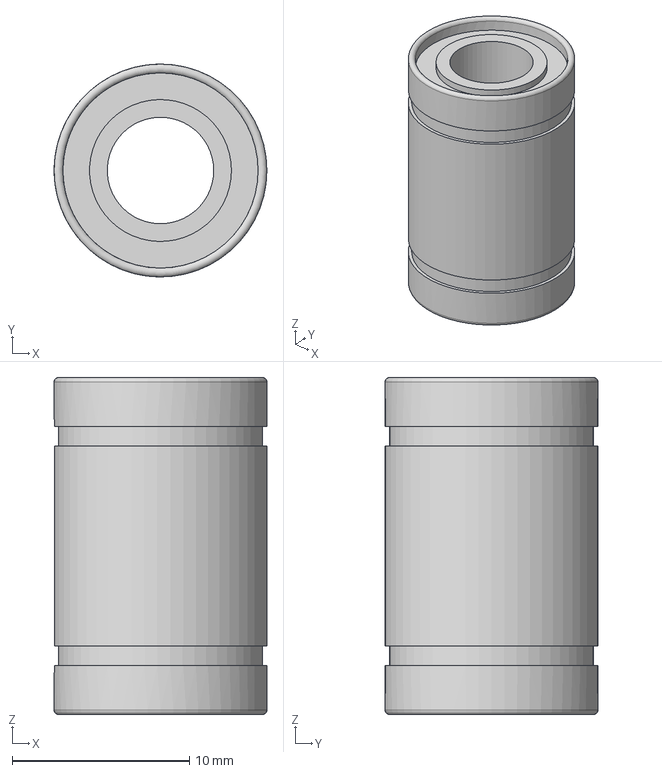
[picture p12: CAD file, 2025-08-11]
CAD_Files/Bearings.stp
12.0 x 12.0 x 19.0 mm

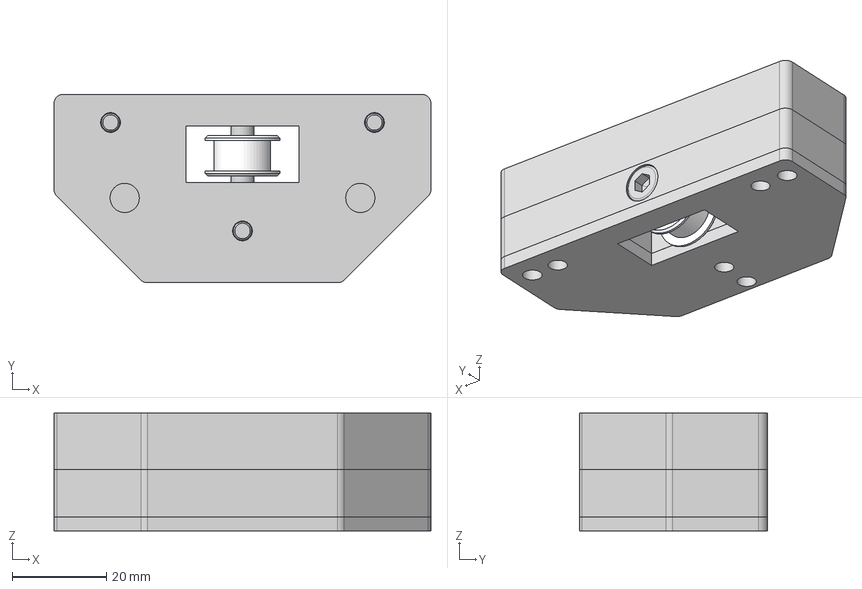
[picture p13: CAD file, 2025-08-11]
CAD_Files/3_Piece_Tensioner.stp
80.0 x 40.0 x 25.0 mm
clamp
tensioner
DIN EN ISO 4762 - M5 x 16 Steel 4.6 Plain
DIN EN ISO 4762 - M4 x 16 Steel 4.6 Plain x 3
GT2 idler pulley (5 mm bore) v1
Tensioner Cap

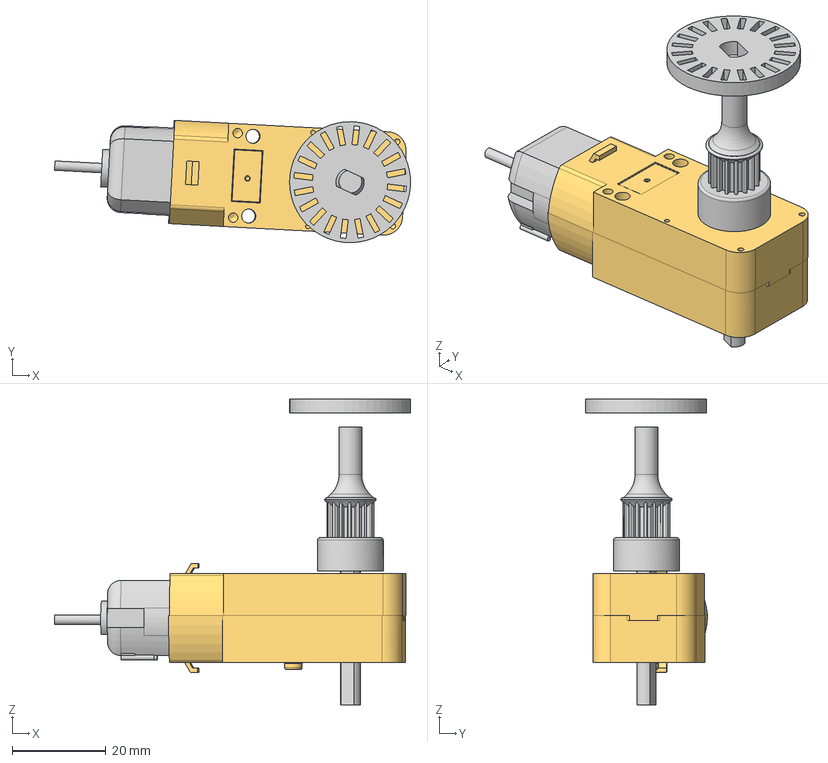
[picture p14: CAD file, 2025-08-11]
CAD_Files/Motor.stp
75.8 x 26.0 x 65.1 mm
Shaft
Motor_1
Gear box
encoder

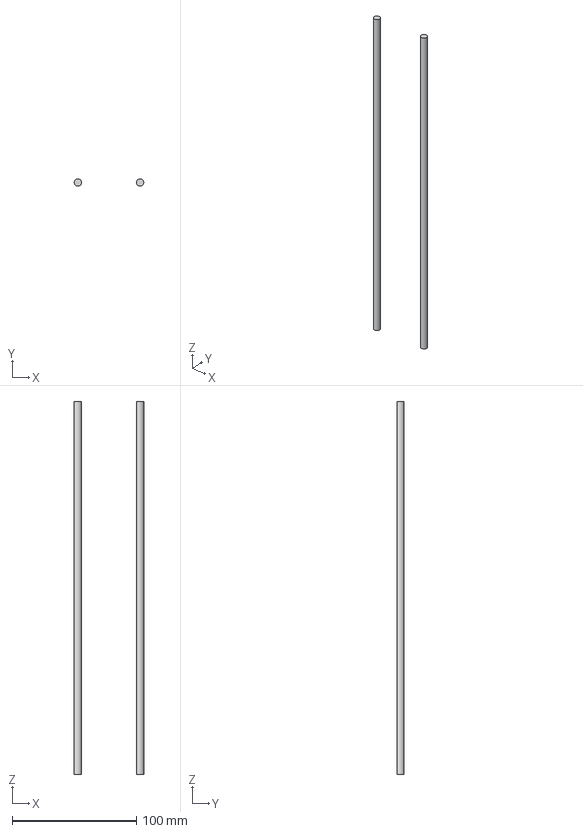
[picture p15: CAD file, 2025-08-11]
CAD_Files/Rods.stp
56.0 x 6.00 x 300.0 mm

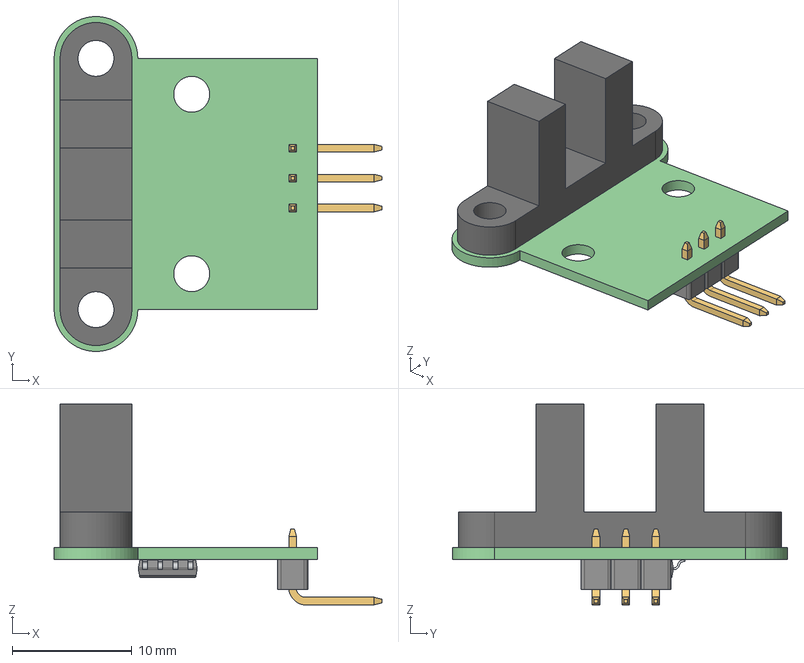
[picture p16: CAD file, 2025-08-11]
CAD_Files/Encoder_Opto_Coupler.stp
27.4 x 28.0 x 16.8 mm
90deg pin header (Adegbuyi Adeyemi) x 3
SOIC8

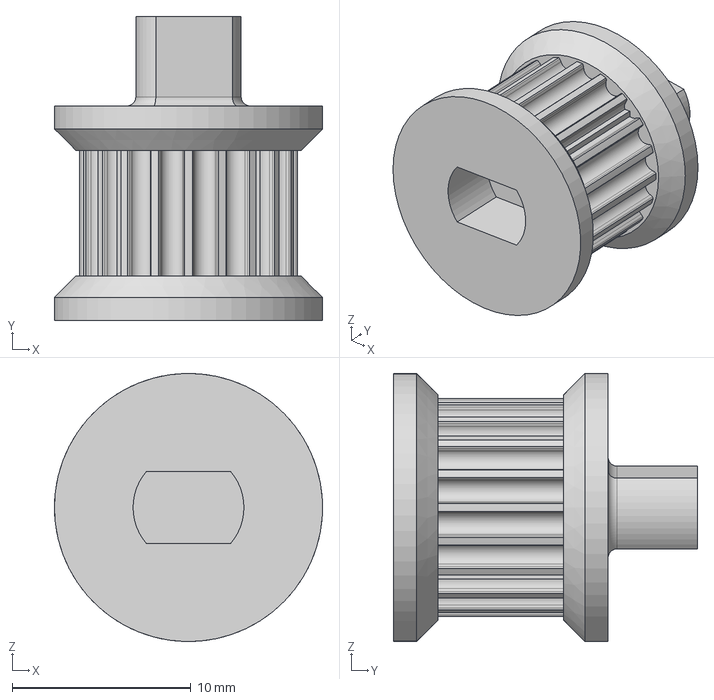
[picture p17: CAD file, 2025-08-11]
CAD_Files/Extension_To_Accomodate_Encoder.stp
15.0 x 17.0 x 15.0 mm

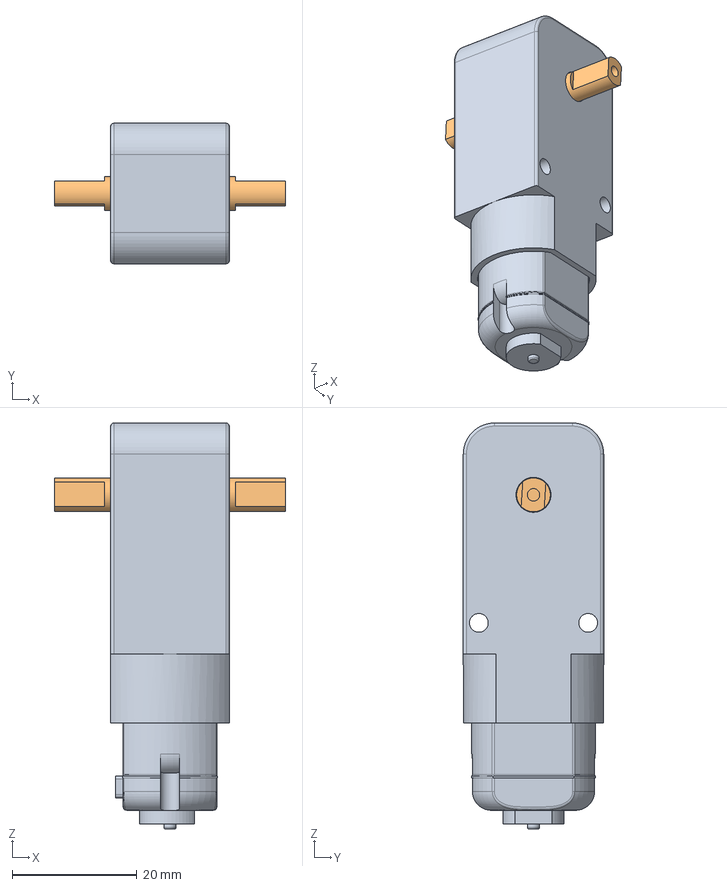
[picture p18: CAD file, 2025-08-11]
CAD_Files/DC_Motor.stp
37.0 x 22.5 x 65.0 mm
Gearbox
output shaft
motor

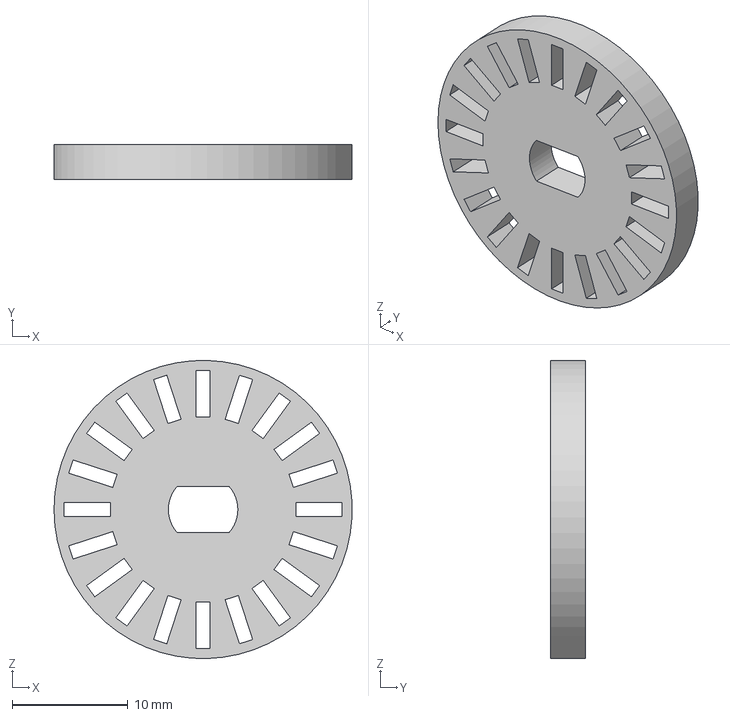
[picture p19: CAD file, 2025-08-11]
CAD_Files/Encoder_disk.stp
25.7 x 3.00 x 25.7 mm

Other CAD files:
CAD_Files/Front_Mount_Pen_Holder.stp
CAD_Files/Pencil.stp
CAD_Files/Extension_For_Motor.stp
CAD_Files/Mount_For_Motor.stp

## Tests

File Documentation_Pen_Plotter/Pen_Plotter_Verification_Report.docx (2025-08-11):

## Pen Plotter Verification Report

### 1. Test protocol doc# 01_MERO_VerP

Test Criteria to Verify: Drawing accuracy and instruction interpretation via ESP32; modularity and open-source accessibility
Test Procedure:

- We uploaded the Nikolaus House G-code wirelessly to ESP32.
- We observed the plotted output for accuracy and refined the code to improve corner precision.
- We performed hardware module replacements and verified that the system could be reassembled within 10 minutes.

Actual Result: Code was successfully optimized; parts were replaced and reassembled efficiently.

### 2. Test protocol doc# 04_MERO_VerP

Test Criteria to Verify: Dry-run feature validation
Test Procedure:

- We enabled the dry-run mode and executed a drawing without engaging the pen-lift mechanism.
- We confirmed that no pen contact occurred during the plotting.

Actual Result: Dry run completed accurately with no Z-axis movement.

### 3. Test protocol doc# 06_MERO_VerP

Test Criteria to Verify: Mechanical strength of the base
Test Procedure:

- We applied a static 1 kg load on the center carriage and let it rest for one hour.
- We then used a vernier caliper to check for structural deformation.

Actual Result: Deformation stayed within acceptable tolerance (under 1 mm).

### 4. Test protocol doc# 07_MERO_VerP

Test Criteria to Verify: User interface operability
Test Procedure:

- We asked two students from different backgrounds to operate the GUI interface.
- We gathered their feedback and improved the interface based on their suggestions.

Actual Result: Initial feedback was negative, but post-modification feedback was positive.

### 5. Test protocol doc# 08_MERO_VerP

Test Criteria to Verify: Assembly and disassembly trial
Test Procedure:

- We completely disassembled and then reassembled the plotter using the provided toolkit.
- We recorded the time and noted any difficulties.

Actual Result: Full disassembly and reassembly completed in approximately 22 minutes.

### 6. Test protocol doc# 10_MERO_VerP

Test Criteria to Verify: Feedback precision via encoders
Test Procedure:

- We moved the pen to known XY coordinates and measured the final position with a scale.
- We compared expected vs actual positions.

Actual Result: Accuracy varied from -2.5 mm to +3 mm; further refinement is in progress.

### 7. Test protocol doc# 11_MERO_VerP

Test Criteria to Verify: Repeated drawing precision
Test Procedure:

- We ran the same drawing (Nikolaus House) 10 times.
- We overlaid the outputs and checked for drift or dimensional errors.

Actual Result: Precision degraded over cycles due to motor heating; accuracy fell to ±4 mm.

### 8. Test protocol doc# 15_MERO_VerP

Test Criteria to Verify: Surface finish check
Test Procedure:

- We plotted long straight lines and checked for ink pooling, unevenness, or wobble.

Actual Result: Vertical accuracy remained within ±2 mm.

### 9. Test protocol doc# 16_MERO_VerP

Test Criteria to Verify: Paper securement test
Test Procedure:

- We used magnetic clamps to secure the paper.
- We simulated vibrations to check if the paper stayed fixed.

Actual Result: Paper remained firmly in place, with deviation under 0.3 mm.

### 10. Test protocol doc# 18_MERO_VerP

Test Criteria to Verify: Motion smoothness
Test Procedure:

- We performed diagonal and continuous motions.
- We examined the encoder's feedback and listened to mechanical noise.

Actual Result: Smoother motion achieved after design improvements.

### 11. Test protocol doc# 19_MERO_VerP

Test Criteria to Verify: Pen grip check
Test Procedure:

- We tested pen mounting using glue and heat-insert nuts.
- We compared plotting accuracy in both setups.

Actual Result: Heat-insert nut showed 50–60% improvement in grip and precision.

### 12. Test protocol doc# 20_MERO_VerP

Test Criteria to Verify: Pen size accommodation
Test Procedure:

- We inserted pens of various diameters (8 mm to 13 mm) and tested alignment.

Actual Result: All pens fit securely; modular design ensures good alignment.

### 13. Test protocol doc# 21_MERO_VerP

Test Criteria to Verify: Command input validation
Test Procedure:

- We ran custom codes to check PWM signals, motor directions, and encoder readings.

Actual Result: All commands executed successfully.

### 14. Test protocol doc# 22_MERO_VerP

Test Criteria to Verify: Pen lift functionality
Test Procedure:

- We toggled pen up/down commands via GUI.
- We measured the actuation time using a stopwatch.

Actual Result: Actuation completed within 500 ms.

### 15. Test protocol doc# 23_MERO_VerP

Test Criteria to Verify: Connectivity testing
Test Procedure:

- We connected to the web interface via both PC and mobile.
- We sent multiple commands and measured response time.

Actual Result: Reliable connectivity; response delay under 7 seconds.

### 16. Test protocol doc# 24_MERO_VerP

Test Criteria to Verify: XY travel consistency
Test Procedure:

- We sent precise travel commands and measured actual pen movement.
- We adjusted belt tension as needed.

Actual Result: Movement was accurate within 2 mm deviation.

### 17. Test protocol doc# 25_MERO_VerP

Test Criteria to Verify: Position tracking accuracy
Test Procedure:

- We compared encoder feedback to expected values after known movements.

Actual Result: Tracking showed >10% error; improvements are ongoing.

### 18. Test protocol doc# 26_MERO_VerP

Test Criteria to Verify: PID loop performance
Test Procedure:

- We applied the load during motion and observed speed correction via PID control.

Actual Result: Current PID tuning is not sufficient; further work is needed.

### 19. Test protocol doc# 27_MERO_VerP

Test Criteria to Verify: Pressure consistency
Test Procedure:

- We adjusted servo angles and tested pen pressure on paper with various pens.

Actual Result: Consistent pressure achieved after calibration.

### 20. Test protocol doc# 28_MERO_VerP

Test Criteria to Verify: Homing routine
Test Procedure:

- We sent over-range coordinates to trigger limit switches.
- We activated the emergency stop and observed homing response.

Actual Result: Homing executed correctly within 10 seconds.

### 21. Test protocol doc# 30_MERO_VerP

Test Criteria to Verify: Safe limit enforcement
Test Procedure:

- We attempted out-of-bounds moves to check limit switch response.

Actual Result: Limit switches triggered correctly and prevented damage.

### 22. Test protocol doc# 32_MERO_VerP

Test Criteria to Verify: Modular upgrade feasibility
Test Procedure:

- We removed and replaced key modules (motor, pen holder, etc.)
- Measured time for hardware swaps.

Actual Result: Upgrades performed in under 10 minutes.

### 23. Test protocol doc# 33_MERO_VerP

Test Criteria to Verify: Open-source tool compatibility
Test Procedure:

- We generated G-code in Inkscape and uploaded it via the Arduino IDE.

Actual Result: Successfully integrated with open-source platforms.

### 24. Test protocol doc# 34_MERO_VerP

Test Criteria to Verify: Expandability
Test Procedure:

- We extended the working area by adjusting firmware limits.
- Paper held using magnetic clamps instead of rails.

Actual Result: System adaptable to larger surfaces.

### 25. Test protocol doc# 35_MERO_VerP

Test Criteria to Verify: BOM cost review
Test Procedure:

- We calculated all material and shipping costs.
- We noted the operating voltage used.

Actual Result: Operating at 9V; costs reviewed and documented.

### 26. Test protocol doc# 36_MERO_VerP

Test Criteria to Verify: Electrical safety
Test Procedure:

- We checked terminal voltages with a multimeter.
- We visually inspected insulation and wiring.

Actual Result: All checks passed; no safety issues found.

### 27. Test protocol doc# 37_MERO_VerP

Test Criteria to Verify: Enclosure safety
Test Procedure:

- We reviewed the component enclosure for airflow and capacity.

Actual Result: Enclosure meets safety and organization standards.

### 28. Test protocol doc# 38_MERO_VerP

Test Criteria to Verify: Emergency stop function
Test Procedure:

- We pressed the E-stop during active plotting.
- We observed system halt and recovery.

Actual Result: E-stop triggered system halt and safe homing.

### 29. Test protocol doc# 40_MERO_VerP

Test Criteria to Verify: Weight verification
Test Procedure:

- We weighed the entire assembled unit.

Actual Result: Total weight is under 3.5 kg.

### 30. Test protocol doc# 41_MERO_VerP

Test Criteria to Verify: Disassembly and portability
Test Procedure:

- We disassembled the system and packed it for transportation.
- Noted any tools needed.

Actual Result: Mostly tool-free; center mount requires bolts.

### 31. Test protocol doc# 43_MERO_VerP

Test Criteria to Verify: Open-source licensing compliance
Test Procedure:

- We reviewed all code used and ensured it complied with open-source licenses.

Actual Result: All software and tools used are open-source compliant.

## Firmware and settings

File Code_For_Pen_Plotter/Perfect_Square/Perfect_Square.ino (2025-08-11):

#include <Arduino.h>
#include <EEPROM.h>

// ==== EEPROM SETTINGS ====
#define EEPROM_SIZE 64
#define EEPROM_ADDR_CORR 0  // Starting address for correction factors

// ==== Pin Definitions ====
#define MOTOR_A_IN1 32
#define MOTOR_A_IN2 14
#define MOTOR_B_IN1 27
#define MOTOR_B_IN2 12

#define LIMIT_X_PIN 18
#define LIMIT_Y_PIN 19
#define ENCODER_A_PIN 34
#define ENCODER_B_PIN 35

#define MAX_PWM 255
#define HOMING_PWM 150
#define LOOP_INTERVAL 20 // ms PID loop
#define SETTLE_DELAY 150 // ms pause at corners

// === Motion parameters ===
const float MM_PER_PULSE = 0.34;

// === Feedforward scaling ===
float dutyScaleA = 0.93;
float dutyScaleB = 1.00;

// === PID Gains ===
float Kp = 4.0;
float Ki = 0.3;
float Kd = 0.05;  // Added small derivative gain for better control

// === Directional correction factors ===
float CORR_RIGHT = 1.0;
float CORR_DOWN  = 1.0;
float CORR_LEFT  = 1.0;
float CORR_UP    = 1.0;

// === Encoder Tracking ===
volatile long pulsesA = 0;
volatile long pulsesB = 0;
volatile int dirA = 0;
volatile int dirB = 0;

// === PID Variables ===
float integralA = 0, prevErrorA = 0;
float integralB = 0, prevErrorB = 0;

// ==== Interrupts ====
void IRAM_ATTR onPulseA() { pulsesA += dirA; }
void IRAM_ATTR onPulseB() { pulsesB += dirB; }

// ==== Movement Queue ====
#define MOVE_QUEUE_SIZE 10
struct MoveCmd {
  String dir;
  float mm;
  int speedPWM;
};
MoveCmd moveQueue[MOVE_QUEUE_SIZE];
int queueStart = 0;
int queueEnd = 0;

bool isMoving = false;
unsigned long settleStartTime = 0;
bool isSettling = false;

// ==== Function prototypes ====
void driveMotor(int motorID, int pwm);
void stopMotors();
int mmToPulses(float mm);
void home();
void moveCoreXY_Optimized(float mmX, float mmY, int speedPWM);
void saveCorrectionFactors();
void loadCorrectionFactors();
void calibrate();
void enqueueMove(String dir, float mm, int speedPWM);
bool dequeueMove(MoveCmd &cmd);

// ==== Movement Queue Functions ====
void enqueueMove(String dir, float mm, int speedPWM) {
  int nextEnd = (queueEnd + 1) % MOVE_QUEUE_SIZE;
  if (nextEnd != queueStart) {
    moveQueue[queueEnd].dir = dir;
    moveQueue[queueEnd].mm = mm;
    moveQueue[queueEnd].speedPWM = speedPWM;
    queueEnd = nextEnd;
  }
}

bool dequeueMove(MoveCmd &cmd) {
  if (queueStart == queueEnd) return false;
  cmd = moveQueue[queueStart];
  queueStart = (queueStart + 1) % MOVE_QUEUE_SIZE;
  return true;
}

// ==== Setup ====
void setup() {
  Serial.begin(115200);
  EEPROM.begin(EEPROM_SIZE);

  pinMode(MOTOR_A_IN1, OUTPUT);
  pinMode(MOTOR_A_IN2, OUTPUT);
  pinMode(MOTOR_B_IN1, OUTPUT);
  pinMode(MOTOR_B_IN2, OUTPUT);

  pinMode(LIMIT_X_PIN, INPUT_PULLUP);
  pinMode(LIMIT_Y_PIN, INPUT_PULLUP);
  pinMode(ENCODER_A_PIN, INPUT_PULLUP);
  pinMode(ENCODER_B_PIN, INPUT_PULLUP);

  attachInterrupt(digitalPinToInterrupt(ENCODER_A_PIN), onPulseA, FALLING);
  attachInterrupt(digitalPinToInterrupt(ENCODER_B_PIN), onPulseB, FALLING);

  loadCorrectionFactors();

  Serial.println("CoreXY ready. Type 'help' for commands.");
}

// ==== Main loop ====
void loop() {
  static MoveCmd currentMove;

  if (!isMoving && !isSettling) {
    if (dequeueMove(currentMove)) {
      float correctedMM = currentMove.mm;
      if (currentMove.dir == "left") correctedMM *= CORR_LEFT;
      else if (currentMove.dir == "up") correctedMM *= CORR_UP;
      else if (currentMove.dir == "right") correctedMM *= CORR_RIGHT;
      else if (currentMove.dir == "down") correctedMM *= CORR_DOWN;

      moveCoreXY_Optimized(
        (currentMove.dir == "left") ? -correctedMM : (currentMove.dir == "right") ? correctedMM : 0,
        (currentMove.dir == "up") ? correctedMM : (currentMove.dir == "down") ? -correctedMM : 0,
        currentMove.speedPWM
      );
      isMoving = true;
    }
  }

  if (isMoving) {
    // Once moveCoreXY_Optimized completes, movement done.
    isMoving = false;
    isSettling = true;
    settleStartTime = millis();
    stopMotors();
  }

  if (isSettling && millis() - settleStartTime >= SETTLE_DELAY) {
    isSettling = false;
  }

  if (Serial.available() && !isMoving && !isSettling) {
    String cmd = Serial.readStringUntil('\n');
    cmd.trim();
    cmd.toLowerCase();

    if (cmd == "home") {
      home();
    }
    else if (cmd.startsWith("left") || cmd.startsWith("right") ||
             cmd.startsWith("up") || cmd.startsWith("down")) {
      int space = cmd.indexOf(' ');
      if (space > 0) {
        String dir = cmd.substring(0, space);
        float mm = cmd.substring(space + 1).toFloat();
        enqueueMove(dir, mm, MAX_PWM * 0.6);
      }
    }
    else if (cmd.startsWith("square")) {
      int space = cmd.indexOf(' ');
      if (space > 0) {
        float side = cmd.substring(space + 1).toFloat();
        enqueueMove("right", side, MAX_PWM * 0.6);
        enqueueMove("down", side, MAX_PWM * 0.6);
        enqueueMove("left", side, MAX_PWM * 0.6);
        enqueueMove("up", side, MAX_PWM * 0.6);
      }
    }
    else if (cmd == "stop") {
      stopMotors();
      queueStart = queueEnd = 0;
    }
    else if (cmd == "calibrate") {
      calibrate();
    }
    else if (cmd == "help") {
      Serial.println("Commands:");
      Serial.println("home                - Home the machine");
      Serial.println("left X / right X    - Move X mm");
      Serial.println("up X / down X       - Move X mm");
      Serial.println("square X            - Draw square of side X mm (right > down > left > up)");
      Serial.println("calibrate           - Run calibration routine");
      Serial.println("stop                - Stop all motion and clear queue");
    }
  }
}

// ==== Motor Control ====
void driveMotor(int motorID, int pwm) {
  int pin1 = (motorID == 0) ? MOTOR_A_IN1 : MOTOR_B_IN1;
  int pin2 = (motorID == 0) ? MOTOR_A_IN2 : MOTOR_B_IN2;

  int out = constrain(abs(pwm), 0, MAX_PWM);
  if (pwm > 0) {
    if (motorID == 0) dirA = 1; else dirB = 1;
    analogWrite(pin1, out); analogWrite(pin2, 0);
  } else if (pwm < 0) {
    if (motorID == 0) dirA = -1; else dirB = -1;
    analogWrite(pin1, 0); analogWrite(pin2, out);
  } else {
    if (motorID == 0) dirA = 0; else dirB = 0;
    analogWrite(pin1, 0); analogWrite(pin2, 0);
  }
}

void stopMotors() {
  driveMotor(0, 0);
  driveMotor(1, 0);
}

// ==== Motion ====
int mmToPulses(float mm) {
  return round(mm / MM_PER_PULSE);
}

void moveCoreXY_Optimized(float mmX, float mmY, int speedPWM) {
  int targetPulsesX = mmToPulses(mmX);
  int targetPulsesY = mmToPulses(mmY);

  int targetA = targetPulsesX + targetPulsesY;
  int targetB = targetPulsesX - targetPulsesY;

  long startA = pulsesA;
  long startB = pulsesB;

  int dirSignA = (targetA >= 0) ? 1 : -1;
  int dirSignB = (targetB >= 0) ? 1 : -1;

  integralA = 0; integralB = 0;
  prevErrorA = 0; prevErrorB = 0;

  unsigned long lastUpdate = millis();

  while (true) {
    unsigned long now = millis();
    if (now - lastUpdate >= LOOP_INTERVAL) {
      lastUpdate = now;

      long currA = pulsesA - startA;
      long currB = pulsesB - startB;

      // Check if movement complete in both motors
      bool doneA = (dirSignA > 0) ? (currA >= targetA) : (currA <= targetA);
      bool doneB = (dirSignB > 0) ? (currB >= targetB) : (currB <= targetB);

      if (doneA && doneB) {
        break;
      }

      int errorA = targetA - currA;
      int errorB = targetB - currB;

      integralA += errorA;
      integralB += errorB;

      float derivA = errorA - prevErrorA;
      float derivB = errorB - prevErrorB;

      float pwmA = (Kp * errorA + Ki * integralA + Kd * derivA) * dutyScaleA;
      float pwmB = (Kp * errorB + Ki * integralB + Kd * derivB) * dutyScaleB;

      prevErrorA = errorA;
      prevErrorB = errorB;

      // Clamp PWM to speed limits
      pwmA = constrain(pwmA, -speedPWM, speedPWM);
      pwmB = constrain(pwmB, -speedPWM, speedPWM);

      driveMotor(0, pwmA);
      driveMotor(1, pwmB);

      // Debug output (can slow down, remove if needed)
      Serial.printf("ErrA: %d, PWM_A: %.1f | ErrB: %d, PWM_B: %.1f\n", errorA, pwmA, errorB, pwmB);
    }
  }
  stopMotors();
}

// ==== Homing ====
void home() {
  Serial.println("Starting homing...");
  while (digitalRead(LIMIT_X_PIN) == HIGH || digitalRead(LIMIT_Y_PIN) == HIGH) {
    int dx = 0, dy = 0;
    if (digitalRead(LIMIT_X_PIN) == HIGH) dx = -50;
    if (digitalRead(LIMIT_Y_PIN) == HIGH) dy = -50;

    int motorA = dx + dy;
    int motorB = dx - dy;

    driveMotor(0, motorA > 0 ? HOMING_PWM : (motorA < 0 ? -HOMING_PWM : 0));
    driveMotor(1, motorB > 0 ? HOMING_PWM : (motorB < 0 ? -HOMING_PWM : 0));
    delay(10);
  }
  stopMotors();
  pulsesA = 0; pulsesB = 0;
  Serial.println("Homed.");
}

// ==== EEPROM Functions ====
void saveCorrectionFactors() {
  EEPROM.put(EEPROM_ADDR_CORR, CORR_RIGHT);
  EEPROM.put(EEPROM_ADDR_CORR + sizeof(float), CORR_DOWN);
  EEPROM.put(EEPROM_ADDR_CORR + 2*sizeof(float), CORR_LEFT);
  EEPROM.put(EEPROM_ADDR_CORR + 3*sizeof(float), CORR_UP);
  EEPROM.commit();
}

void loadCorrectionFactors() {
  EEPROM.get(EEPROM_ADDR_CORR, CORR_RIGHT);
  EEPROM.get(EEPROM_ADDR_CORR + sizeof(float), CORR_DOWN);
  EEPROM.get(EEPROM_ADDR_CORR + 2*sizeof(float), CORR_LEFT);
  EEPROM.get(EEPROM_ADDR_CORR + 3*sizeof(float), CORR_UP);

  if (isnan(CORR_RIGHT) || isnan(CORR_DOWN) || isnan(CORR_LEFT) || isnan(CORR_UP)) {
    CORR_RIGHT = CORR_DOWN = CORR_LEFT = CORR_UP = 1.0;
  }
  Serial.printf("Loaded Corrections: R=%.3f D=%.3f L=%.3f U=%.3f\n", CORR_RIGHT, CORR_DOWN, CORR_LEFT, CORR_UP);
}

// ==== Calibration Routine ====
void calibrate() {
  Serial.println("Starting calibration: target = 50mm per move.");
  home();
  delay(500);

  float measured[4];
  String dirNames[4] = {"right", "down", "left", "up"};

  for (int i = 0; i < 4; i++) {
    enqueueMove(dirNames[i], 50, MAX_PWM * 0.6);
    while (isMoving || isSettling || queueStart != queueEnd) { loop(); }
    Serial.printf("Measure %s move (mm): ", dirNames[i].c_str());
    while (!Serial.available()) delay(10);
    measured[i] = Serial.readStringUntil('\n').toFloat();
  }

  CORR_RIGHT = 50.0 / measured[0];
  CORR_DOWN  = 50.0 / measured[1];
  CORR_LEFT  = 50.0 / measured[2];
  CORR_UP    = 50.0 / measured[3];

  saveCorrectionFactors();

  Serial.printf("New Corrections: R=%.3f D=%.3f L=%.3f U=%.3f\n", CORR_RIGHT, CORR_DOWN, CORR_LEFT, CORR_UP);
  Serial.println("Calibration complete.");
}

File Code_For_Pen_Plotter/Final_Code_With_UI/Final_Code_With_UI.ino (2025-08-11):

#include <Arduino.h>
#include <EEPROM.h>
#include <WiFi.h>
#include <WebServer.h>

// ==== EEPROM SETTINGS ====
#define EEPROM_SIZE 128
#define EEPROM_ADDR_CORR 0 // Starting address for correction factors
#define EEPROM_ADDR_POS (EEPROM_ADDR_CORR + 4 * sizeof(float)) // store emergency stop pulsesA, pulsesB

// ==== Pin Definitions ====
#define MOTOR_A_IN1 32
#define MOTOR_A_IN2 14
#define MOTOR_B_IN1 27
#define MOTOR_B_IN2 12

#define LIMIT_X_PIN 18
#define LIMIT_Y_PIN 19
#define ENCODER_A_PIN 34
#define ENCODER_B_PIN 35

#define EMERGENCY_STOP_PIN 33

#define MAX_PWM 255
#define HOMING_PWM 150
#define LOOP_INTERVAL 20 // ms PID loop
#define SETTLE_DELAY 150 // ms pause at corners

// === Motion parameters ===
// The MM_PER_PULSE value has been calibrated using the provided data:
// 46mm divided by 30 pulses = 1.5333mm per pulse.
const float MM_PER_PULSE = 1.5333;

// === Feedforward scaling ===
// Calibrated with user data: 30 pulses (target) / 31 pulses (actual) = 0.96774
float dutyScaleA = 0.96774;
float dutyScaleB = 0.96774;

// === PID Gains ===
float Kp = 5.0; // Increased from 4.0 for a stronger, faster response to errors
float Ki = 0.5; // Increased from 0.3 to better correct for steady-state errors
float Kd = 0.1; // Increased from 0.05 to help dampen overshoot from the higher Kp

// === Directional correction factors ===
float CORR_RIGHT = 1.0;
float CORR_DOWN = 1.0;
float CORR_LEFT = 1.0;
float CORR_UP = 1.0;

// === Encoder Tracking ===
volatile long pulsesA = 0;
volatile long pulsesB = 0;
volatile int dirA = 0;
volatile int dirB = 0;

// Saved position before emergency stop
long savedPulsesA = 0;
long savedPulsesB = 0;

// === PID Variables ===
float integralA = 0, prevErrorA = 0;
float integralB = 0, prevErrorB = 0;

// ==== Interrupts ====
void IRAM_ATTR onPulseA() { pulsesA += dirA; }
void IRAM_ATTR onPulseB() { pulsesB += dirB; }

// ==== Movement Queue ====
#define MOVE_QUEUE_SIZE 10
struct MoveCmd {
    String dir;
    int pulses;
    int speedPWM;
};
MoveCmd moveQueue[MOVE_QUEUE_SIZE];
int queueStart = 0;
int queueEnd = 0;

bool isMoving = false;
unsigned long settleStartTime = 0;
bool isSettling = false;

bool emergencyStopActive = false;

// === WiFi & Web Server Configuration ===
// *** Changed to Access Point mode ***
const char* ssid = "ESP32";
const char* password = "12345";

WebServer server(80);

// ==== Function prototypes ====
void driveMotor(int motorID, int pwm);
void stopMotors();
void home();
void moveCoreXY_Optimized(float mmX, float mmY, int speedPWM);
void moveCoreXY_Pulses(int pulsesX, int pulsesY, int speedPWM);
void saveCorrectionFactors();
void loadCorrectionFactors();
void calibrate();
void enqueueMove(String dir, float mm, int speedPWM);
void enqueueMovePulses(String dir, int pulses, int speedPWM);
bool dequeueMove(MoveCmd &cmd);
void saveEmergencyPosition(long pulsesA_val, long pulsesB_val);
void loadEmergencyPosition(long &pulsesA_val, long &pulsesB_val);
void handleEmergencyStop();
void nicolas(int sidePulses); // New function prototype to accept pulse count

// ==== Web Server Handlers ====
void handleRoot();
void handleCommand();

// ==== Movement Queue Functions ====
void enqueueMove(String dir, float mm, int speedPWM) {
    int nextEnd = (queueEnd + 1) % MOVE_QUEUE_SIZE;
    if (nextEnd != queueStart) {
        moveQueue[queueEnd].dir = dir;
        moveQueue[queueEnd].pulses = round(mm / MM_PER_PULSE); // Convert mm to pulses
        moveQueue[queueEnd].speedPWM = speedPWM;
        queueEnd = nextEnd;
    }
}

void enqueueMovePulses(String dir, int pulses, int speedPWM) {
    int nextEnd = (queueEnd + 1) % MOVE_QUEUE_SIZE;
    if (nextEnd != queueStart) {
        moveQueue[queueEnd].dir = dir;
        moveQueue[queueEnd].pulses = pulses;
        moveQueue[queueEnd].speedPWM = speedPWM;
        queueEnd = nextEnd;
    }
}

bool dequeueMove(MoveCmd &cmd) {
    if (queueStart == queueEnd) return false;
    cmd = moveQueue[queueStart];
    queueStart = (queueStart + 1) % MOVE_QUEUE_SIZE;
    return true;
}

// ==== Setup ====
void setup() {
    Serial.begin(115200);
    EEPROM.begin(EEPROM_SIZE);

    pinMode(MOTOR_A_IN1, OUTPUT);
    pinMode(MOTOR_A_IN2, OUTPUT);
    pinMode(MOTOR_B_IN1, OUTPUT);
    pinMode(MOTOR_B_IN2, OUTPUT);

    pinMode(LIMIT_X_PIN, INPUT_PULLUP);
    pinMode(LIMIT_Y_PIN, INPUT_PULLUP);
    pinMode(ENCODER_A_PIN, INPUT_PULLUP);
    pinMode(ENCODER_B_PIN, INPUT_PULLUP);

    pinMode(EMERGENCY_STOP_PIN, INPUT_PULLUP); // Emergency stop button, active LOW

    attachInterrupt(digitalPinToInterrupt(ENCODER_A_PIN), onPulseA, FALLING);
    attachInterrupt(digitalPinToInterrupt(ENCODER_B_PIN), onPulseB, FALLING);

    loadCorrectionFactors();

    // Load saved emergency position, if any
    loadEmergencyPosition(savedPulsesA, savedPulsesB);

    // === WiFi & Web Server Setup ===
    // *** Changed to Access Point mode for direct connection from phone/PC ***
    Serial.printf("Creating Access Point: %s\n", ssid);
    WiFi.softAP(ssid, password);
    IPAddress IP = WiFi.softAPIP();
    Serial.print("AP IP Address: ");
    Serial.println(IP);
    
    server.on("/", handleRoot);
    server.on("/command", handleCommand);
    server.begin();

    Serial.println("CoreXY ready. Use the web interface to control it.");
}
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
